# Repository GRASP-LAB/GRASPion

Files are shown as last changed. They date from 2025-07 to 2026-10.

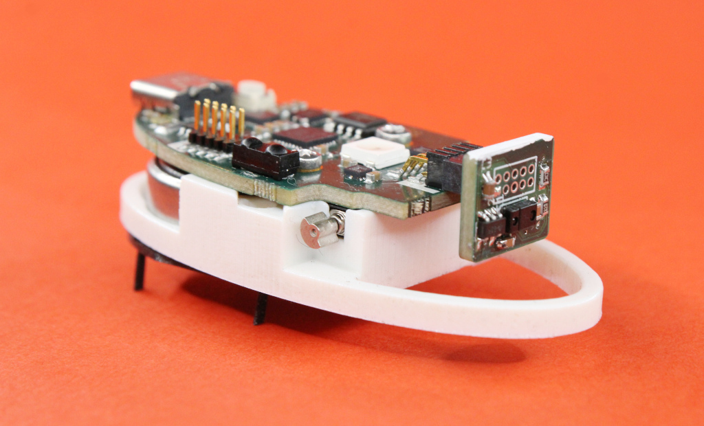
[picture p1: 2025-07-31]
images/bot.jpg

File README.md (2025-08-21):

# GRASPion
The GRASPion is an intelligent bristlebot deisgned for research and education purposes based around
the Adafruit QTPy SAMD21, making it extremely easy-to-use through the Arduino environment. It relies
on two vibrating motors embedded in the bot to move around, and thanks to the carefuly design of its
body and legs available here, it can execute controlled trajectories, by moving straight or turning,
making it a new platform for the experimental study of active matter. It achieves higher velocities
(approx. 15 cm/s) and is capable of higher computing power, than previous types of such bots.



The physical properties of the bot and the results of the examples in this repository are given in
our technical paper (see here). The GRASPion, with a printed and fully assembled circuit board, 3D
printed body, battery, motors and legs is available for order through
[graspion.be](https://graspion.be).

## 3D printing
The bot is made out of three 3D printed objects: the chassis, the legs and the wedge plate in
between them. The STL files of the thre can be found in the printing directory.

### The chassis
The chassis (or the body) is printed out of ABS plastic using the Stratasys J35 PolyJet
printer. This allows for a high resolution print, needed in order to properly fit the vibrating
motors and the battery, and giving a hard body to the robot in order to handle eventual collisions.

### The legs
The legs and wedge plate are printed out of PLA, and we find that the Prusament PLA Prusa Galaxy
handles well and gives consistently reproducible results, using the Prusa XL printer, on the
Structural setting, with 15% infill. It is very important that the legs are printed one-by-one, and
not multiple legs at the same time, since this significantly alters layer adhesion and finally
flexibility of the legs. The wedge plate is printed using the same material.

## Arduino setup

We recommend using the legay Arduino IDE (1.8.19). In order to compile and upload the sketch, you
will need to use the following settings:

| Setting | Value |
| --- | --- |
| Board | Adafruit QT Py M0(SAMD21) ([see here](https://learn.adafruit.com/add-boards-arduino-v164/setup))|
| Optimization |  Ofast  |
| USB Stack |  TinyUSB  |

The libraries that are needed to sucessfully compile the code are:

| Library | Link |
| --- | --- |
| Adafruit Neopixel | https://github.com/adafruit/Adafruit_NeoPixel |
| Adafruit DMA neopixel | https://github.com/adafruit/Adafruit_NeoPixel_ZeroDMA  |
| Adafruit_APDS9960 | https://github.com/adafruit/Adafruit_APDS9960 |
| Adafruit_MLX90393 | https://github.com/adafruit/Adafruit_MLX90393_Library  |
| Adafruit Unified Sensor | https://github.com/adafruit/Adafruit_Sensor |
| Adafruit_BusIO | https://github.com/adafruit/Adafruit_BusIO |
| Arduino-IRremote | https://github.com/Arduino-IRremote/Arduino-IRremote |

The bot has to be turned on in order to compile. In order for the port to appear, it is enough to press the power 
button once. The battery isn't required in order to upload the firmware. Caveat: if the board is removed from the body and 
disconnected from the batter, and subsequently reassembled, the bot needs to be plugged into a charger or live USB-C
cable in order for it to start running again.

## Code examples

Two code examples have been included in the examples directory, one which includes basic remote
control along with a preprogrammed diffusuive motion, and a second one which includes color emission
and synchronization (see PDF for details), Along with these examples, an bash upload script is
included to facilitate uploading to large numbers of bots through the use of a USB hub. The upload
script relies on [arduino-cli](https://github.com/arduino/arduino-cli), which can easily be
installed on Linux distributions.

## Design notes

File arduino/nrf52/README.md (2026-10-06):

# GRASPion Head nRF52832 Arduino support

This directory contains the Arduino support files for the nRF52832 / u-blox ANNA-B112 used in the GRASPion Head.

GRASPion uses three microcontrollers:

- SAMD21 — Body controller
- STM32U575 — Head main controller
- nRF52832 / ANNA-B112 — Head wireless controller

The nRF52 package is based on the Adafruit nRF52 Arduino core 1.7.0 and adds the `graspionHead` board variant.

## GRASPion Head nRF52832 pin mapping

### LED

- P0.15 — built-in LED

### Application UART to STM32U575

- P0.27 TX -> STM32 PA3 / LPUART1_RX
- P0.28 RX <- STM32 PA2 / LPUART1_TX

### Bootloader DFU UART

- P0.29 TX
- P0.30 RX
- 115200 baud

The bootloader UART is intentionally different from the application UART.

### I2C

- P0.16 — SDA
- P0.18 — SCL

### I2S slave RX

- P0.03 — SD / DI
- P0.02 — WS / LRCK
- P0.31 — SCK / BCLK

### Low-frequency clock

The GRASPion Head does not use an external 32.768 kHz crystal for the ANNA-B112. The variant therefore uses the nRF52832 internal LF RC oscillator (`USE_LFRC`).

## Arduino Boards Manager installation

After the first package release has been generated, add this URL to **Arduino IDE -> Preferences -> Additional Boards Manager URLs**:

```text
https://raw.githubusercontent.com/GRASP-LAB/GRASPion/main/package_graspion_index.json
```

Then open **Boards Manager**, search for **GRASPion**, install the package and select:

```text
GRASPion Head nRF52832
```

## Building a package release

The workflow `.github/workflows/build-graspion-nrf52-package.yml` creates the Boards Manager package.

From GitHub:

1. Open **Actions**.
2. Select **Build GRASPion nRF52 Arduino package**.
3. Select **Run workflow**.
4. Enter the package version, for example `1.0.0`.

The workflow:

1. downloads Adafruit nRF52 Arduino core 1.7.0;
2. appends the GRASPion Head board definition;
3. injects `variants/graspionHead`;
4. builds the `.tar.bz2` platform archive;
5. calculates its SHA-256 checksum and size;
6. creates or updates the GitHub release;
7. updates `package_graspion_index.json`.

## Source files

- `variants/graspionHead/variant.h` — board pin/peripheral definitions
- `variants/graspionHead/variant.cpp` — Arduino pin-to-nRF GPIO mapping and variant initialization
- `graspionHead.boards.txt` — board definition appended to Adafruit `boards.txt` during packaging
- `build_package.py` — package/index generator

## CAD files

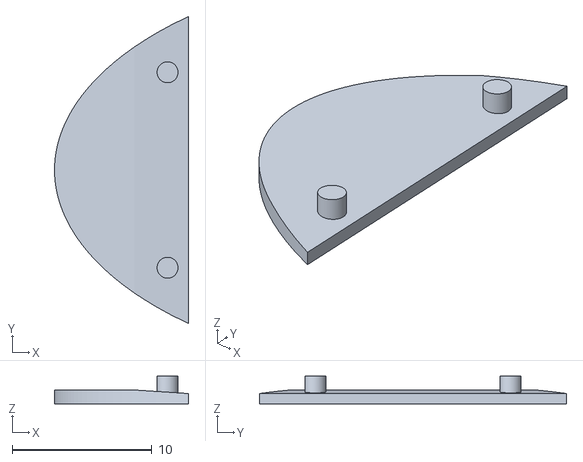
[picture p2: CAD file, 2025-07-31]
prints/Wedge plate.stl
9.60 x 22.0 x 2.00

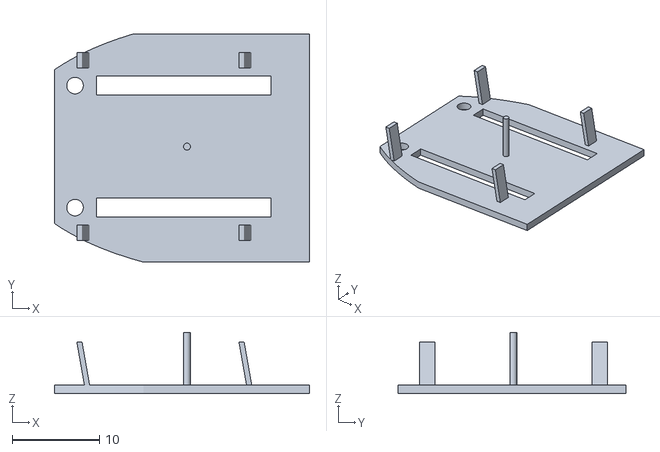
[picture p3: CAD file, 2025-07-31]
prints/Leg plate - rectangular.stl
29.3 x 26.2 x 7.00

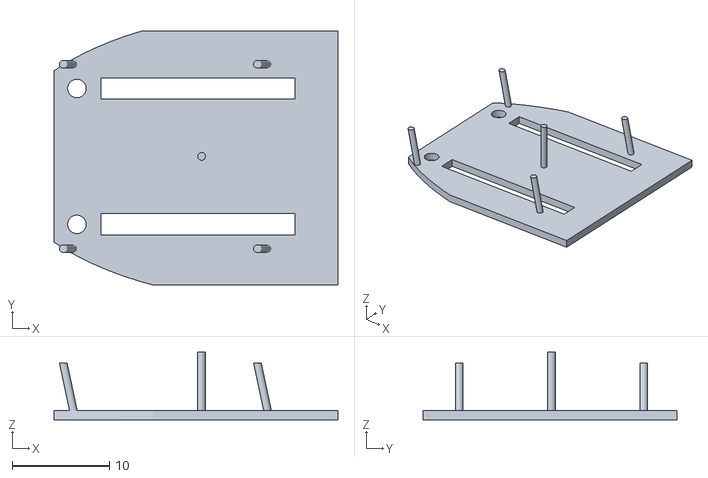
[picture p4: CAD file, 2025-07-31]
prints/Leg plate - circular.stl
29.3 x 26.2 x 7.00

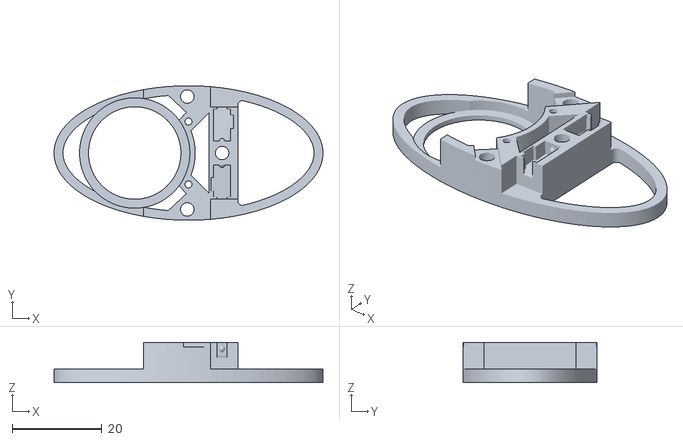
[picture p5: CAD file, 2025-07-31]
prints/GRASPion body.stl
60.0 x 30.0 x 9.00

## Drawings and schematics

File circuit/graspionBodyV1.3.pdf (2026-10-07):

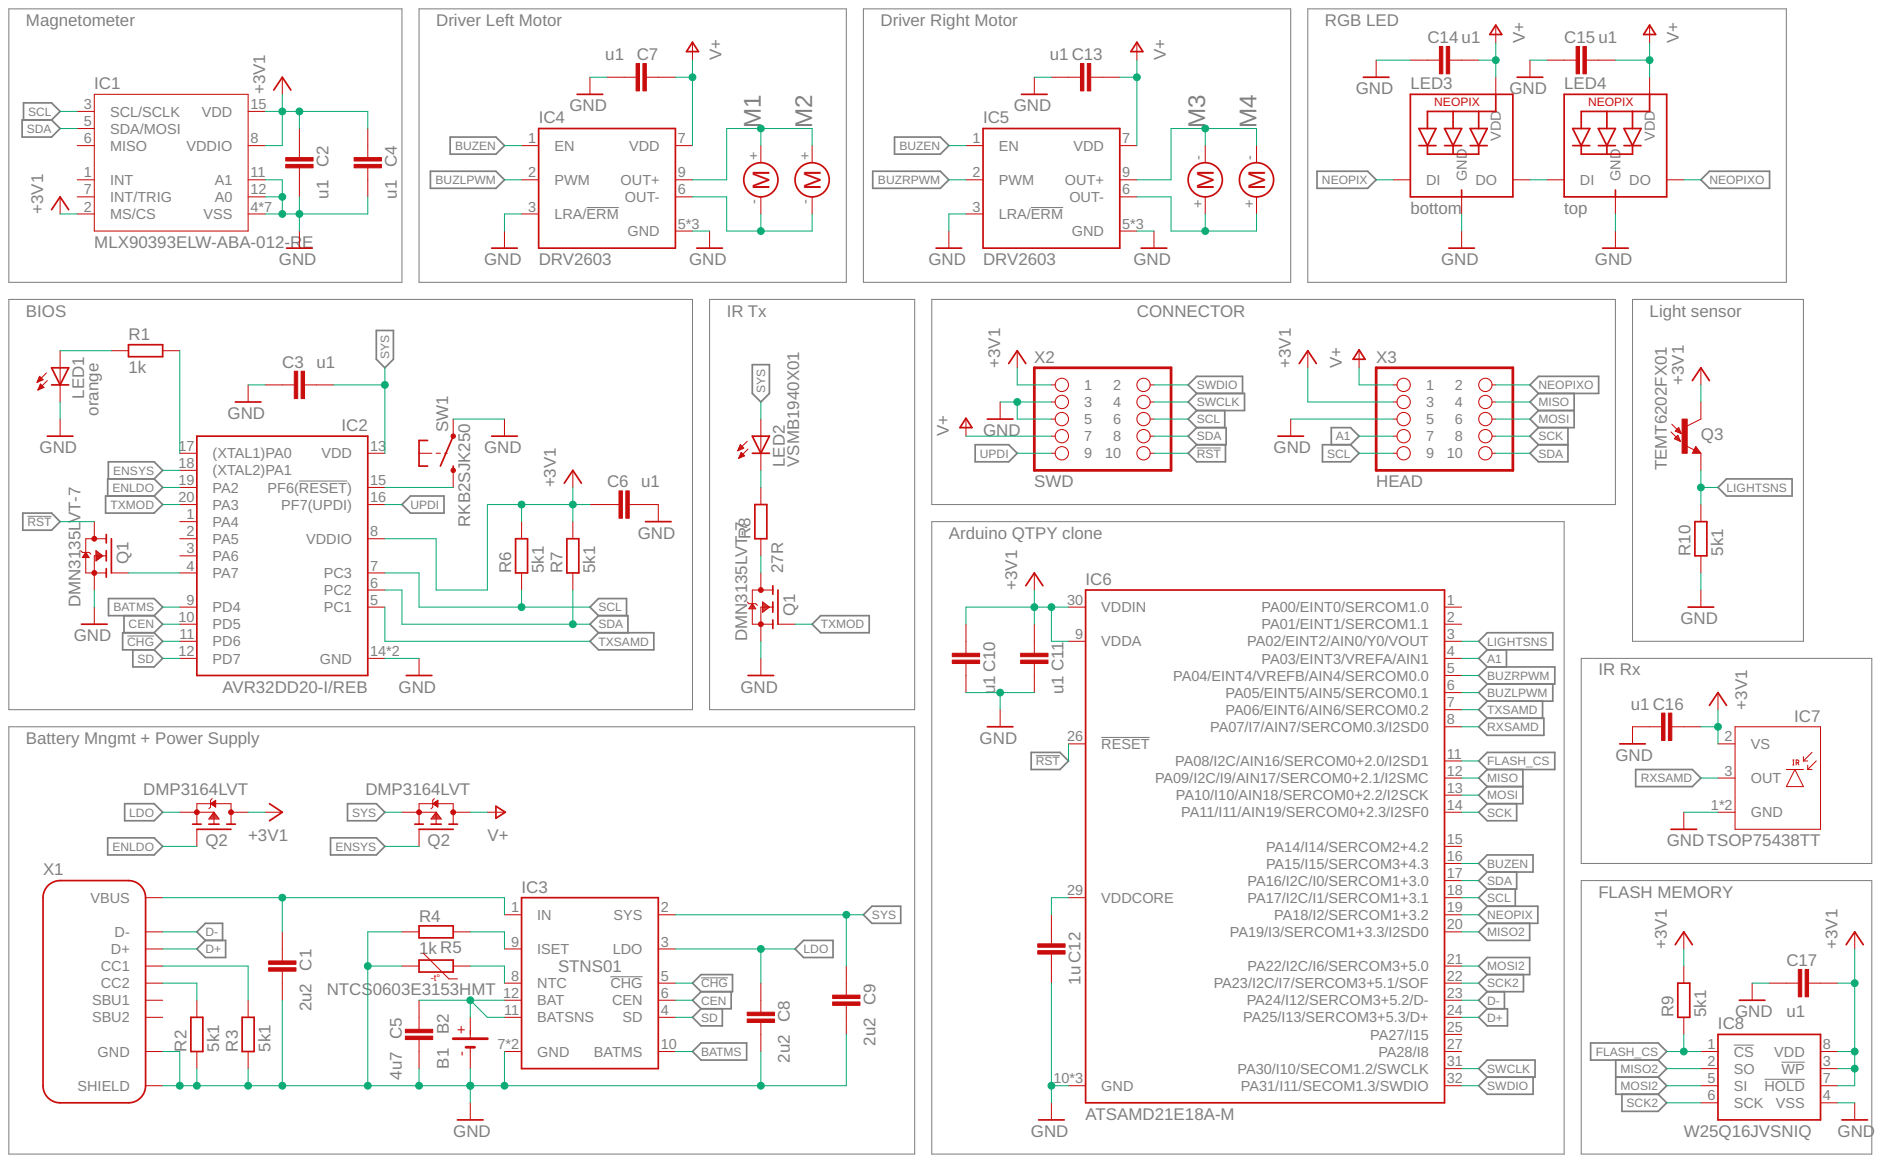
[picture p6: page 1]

Battery Mngmt + Power Supply

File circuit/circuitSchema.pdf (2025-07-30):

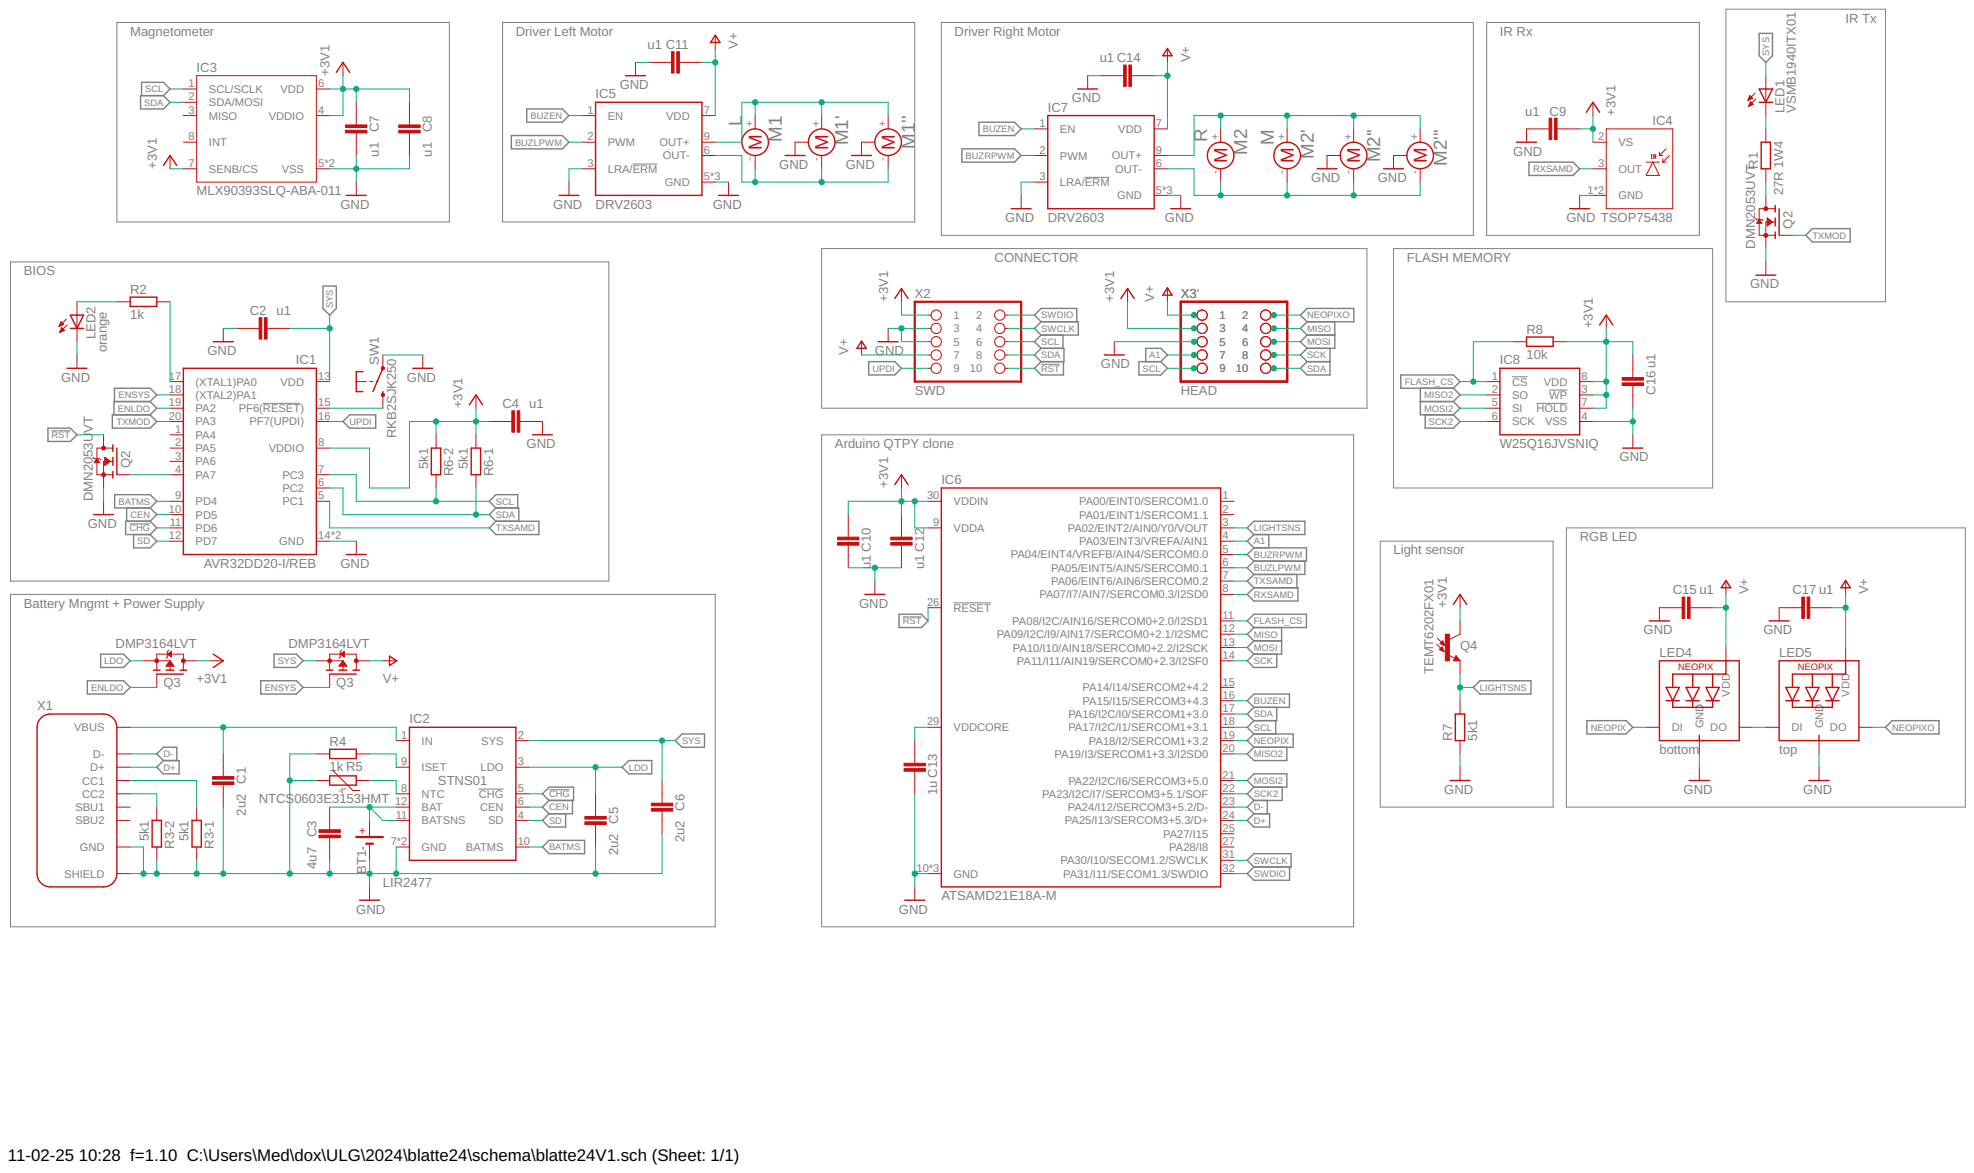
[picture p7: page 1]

Battery Mngmt + Power Supply

11-02-25 10:28 f=1.10 C:\Users\Med\dox\ULG\2024\blatte24\schema\blatte24V1.sch (Sheet: 1/1)

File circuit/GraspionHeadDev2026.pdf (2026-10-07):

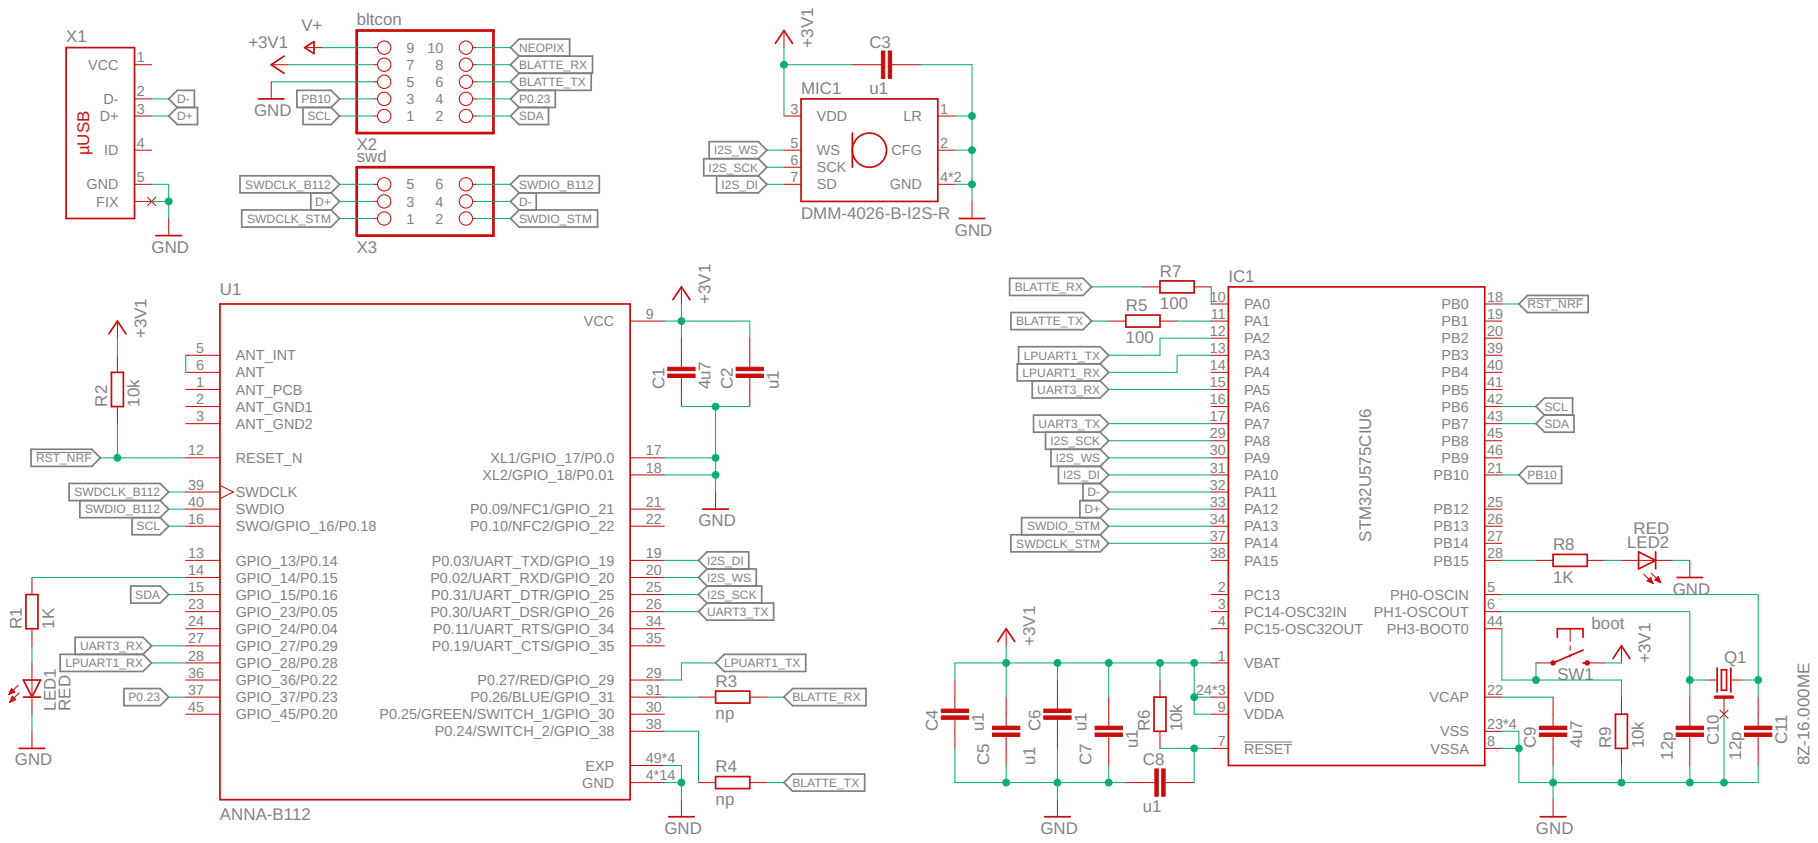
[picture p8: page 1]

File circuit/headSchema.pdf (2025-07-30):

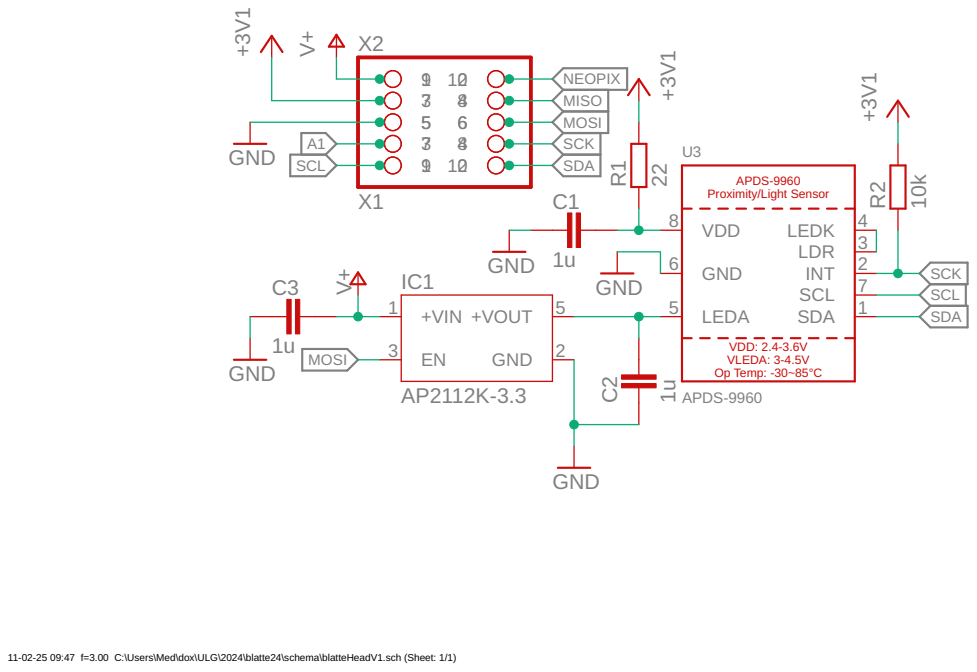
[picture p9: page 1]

11-02-25 09:47 f=3.00 C:\Users\Med\dox\ULG\2024\blatte24\schema\blatteHeadV1.sch (Sheet: 1/1)

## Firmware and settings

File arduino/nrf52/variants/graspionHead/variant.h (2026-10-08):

#ifndef _VARIANT_GRASPIONHEAD_
#define _VARIANT_GRASPIONHEAD_

/*
 * Graspion Head
 * ANNA-B112 / nRF52832
 */

#define VARIANT_MCK (64000000ul)

/*
 * No external 32.768 kHz crystal on Graspion Head.
 * Use internal LF RC oscillator.
 */
#define USE_LFRC

#include "WVariant.h"

#ifdef __cplusplus
extern "C"
{
#endif

/*------------------------------------------------------------------*/
/* Pins
 *------------------------------------------------------------------*/

#define PINS_COUNT           (32u)
#define NUM_DIGITAL_PINS     (32u)
#define NUM_ANALOG_INPUTS    (8u)
#define NUM_ANALOG_OUTPUTS   (0u)

/*------------------------------------------------------------------*/
/* LED
 *
 * P0.15
 *------------------------------------------------------------------*/

#define PIN_LED1             (15)
#define LED_BUILTIN          PIN_LED1
#define LED_BLUE             PIN_LED1
#define LED_STATE_ON         1

/*------------------------------------------------------------------*/
/* Analog inputs
 *
 * nRF52832 SAADC:
 *
 * AIN0 = P0.02
 * AIN1 = P0.03
 * AIN2 = P0.04
 * AIN3 = P0.05
 * AIN4 = P0.28
 * AIN5 = P0.29
 * AIN6 = P0.30
 * AIN7 = P0.31
 *
 * Some of these pins are also assigned to other peripherals on the
 * Graspion Head PCB.
 *------------------------------------------------------------------*/

#define PIN_A0               (2)
#define PIN_A1               (3)
#define PIN_A2               (4)
#define PIN_A3               (5)
#define PIN_A4               (28)
#define PIN_A5               (29)
#define PIN_A6               (30)
#define PIN_A7               (31)

static const uint8_t A0 = PIN_A0;
static const uint8_t A1 = PIN_A1;
static const uint8_t A2 = PIN_A2;
static const uint8_t A3 = PIN_A3;
static const uint8_t A4 = PIN_A4;
static const uint8_t A5 = PIN_A5;
static const uint8_t A6 = PIN_A6;
static const uint8_t A7 = PIN_A7;

#define ADC_RESOLUTION       14

/*------------------------------------------------------------------*/
/* NFC
 *------------------------------------------------------------------*/

#define PIN_NFC1             (9)
#define PIN_NFC2             (10)

/*------------------------------------------------------------------*/
/* Single application UART: Serial
 *
 * nRF52832 exposes one UARTE peripheral through the Adafruit core.
 * GRASPion therefore defines only Serial; no Serial1/Serial2 pins are
 * declared by this variant.
 *
 * nRF P0.29 TX -> STM32 RX
 * nRF P0.30 RX <- STM32 TX
 *------------------------------------------------------------------*/

#define PIN_SERIAL_TX        (29)
#define PIN_SERIAL_RX        (30)

/*------------------------------------------------------------------*/
/* I2C
 *
 * SDA = P0.16
 * SCL = P0.18
 *------------------------------------------------------------------*/

#define WIRE_INTERFACES_COUNT 1

#define PIN_WIRE_SDA         (16u)
#define PIN_WIRE_SCL         (18u)

static const uint8_t SDA = PIN_WIRE_SDA;
static const uint8_t SCL = PIN_WIRE_SCL;

/*------------------------------------------------------------------*/
/* SPI
 *
 * No default SPI bus assigned yet.
 *------------------------------------------------------------------*/

#define SPI_INTERFACES_COUNT 0

/*------------------------------------------------------------------*/
/* I2S - slave RX only
 *
 * DI / SD   = P0.03
 * WS / LRCK = P0.02
 * SCK/BCLK  = P0.31
 *
 * MCK is not used.
 *------------------------------------------------------------------*/

#define I2S_INTERFACES_COUNT 1

#define PIN_I2S_SD           (3u)
#define PIN_I2S_FS           (2u)
#define PIN_I2S_SCK          (31u)

#ifdef __cplusplus
}
#endif

#endif // _VARIANT_GRASPIONHEAD_

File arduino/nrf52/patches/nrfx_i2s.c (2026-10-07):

/**
 * Copyright (c) 2015 - 2021, Nordic Semiconductor ASA
 *
 * All rights reserved.
 *
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
 * 3. Neither the name of Nordic Semiconductor ASA nor the names of its
 *    contributors may be used to endorse or promote products derived from this
 *    software without specific prior written permission.
 *
 * 4. This software, with or without modification, must only be used with a
 *    Nordic Semiconductor ASA integrated circuit.
 *
 * 5. Any software provided in binary form under this license must not be reverse
 *    engineered, decompiled, modified and/or disassembled.
 *
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
 */

#include <nrfx.h>

#if NRFX_CHECK(NRFX_I2S_ENABLED)

#include <nrfx_i2s.h>
#include <hal/nrf_gpio.h>

#define NRFX_LOG_MODULE I2S
#include <nrfx_log.h>

#define EVT_TO_STR(event)                                         \
    (event == NRF_I2S_EVENT_RXPTRUPD ? "NRF_I2S_EVENT_RXPTRUPD" : \
    (event == NRF_I2S_EVENT_TXPTRUPD ? "NRF_I2S_EVENT_TXPTRUPD" : \
    (event == NRF_I2S_EVENT_STOPPED  ? "NRF_I2S_EVENT_STOPPED"  : \
                                       "UNKNOWN EVENT")))

#if !defined(USE_WORKAROUND_FOR_I2S_STOP_ANOMALY) &&                               \
    (defined(NRF52832_XXAA) || defined(NRF52832_XXAB) || defined(NRF52840_XXAA) || \
     defined(NRF9160_XXAA))
#define USE_WORKAROUND_FOR_I2S_STOP_ANOMALY 1
#endif

typedef struct
{
    nrfx_i2s_data_handler_t handler;
    nrfx_drv_state_t        state;

    bool use_rx         : 1;
    bool use_tx         : 1;
    bool rx_ready       : 1;
    bool tx_ready       : 1;
    bool buffers_needed : 1;
    bool buffers_reused : 1;

    uint16_t            buffer_size;
    nrfx_i2s_buffers_t  next_buffers;
    nrfx_i2s_buffers_t  current_buffers;
} i2s_control_block_t;
static i2s_control_block_t m_cb;

static void configure_pins(nrfx_i2s_config_t const * p_config)
{
    uint32_t mck_pin, sdout_pin, sdin_pin;

    if (p_config->mode == NRF_I2S_MODE_MASTER)
    {
        nrf_gpio_cfg_output(p_config->sck_pin);
        nrf_gpio_cfg_output(p_config->lrck_pin);
    }
    else
    {
        nrf_gpio_cfg_input(p_config->sck_pin,  NRF_GPIO_PIN_NOPULL);
        nrf_gpio_cfg_input(p_config->lrck_pin, NRF_GPIO_PIN_NOPULL);
    }

    if (p_config->mck_pin != NRFX_I2S_PIN_NOT_USED)
    {
        mck_pin = p_config->mck_pin;
        nrf_gpio_cfg_output(mck_pin);
    }
    else
    {
        mck_pin = NRF_I2S_PIN_NOT_CONNECTED;
    }

    if (p_config->sdout_pin != NRFX_I2S_PIN_NOT_USED)
    {
        sdout_pin = p_config->sdout_pin;
        nrf_gpio_cfg_output(sdout_pin);
    }
    else
    {
        sdout_pin = NRF_I2S_PIN_NOT_CONNECTED;
    }

    if (p_config->sdin_pin != NRFX_I2S_PIN_NOT_USED)
    {
        sdin_pin = p_config->sdin_pin;
        nrf_gpio_cfg_input(sdin_pin, NRF_GPIO_PIN_NOPULL);
    }
    else
    {
        sdin_pin = NRF_I2S_PIN_NOT_CONNECTED;
    }

    nrf_i2s_pins_set(NRF_I2S,
                     p_config->sck_pin,
                     p_config->lrck_pin,
                     mck_pin,
                     sdout_pin,
                     sdin_pin);
}

nrfx_err_t nrfx_i2s_init(nrfx_i2s_config_t const * p_config,
                         nrfx_i2s_data_handler_t   handler)
{
    NRFX_ASSERT(p_config);
    NRFX_ASSERT(handler);

    nrfx_err_t err_code;

    if (m_cb.state != NRFX_DRV_STATE_UNINITIALIZED)
    {
        err_code = NRFX_ERROR_INVALID_STATE;
        NRFX_LOG_WARNING("Function: %s, error code: %s.",
                         __func__,
                         NRFX_LOG_ERROR_STRING_GET(err_code));
        return err_code;
    }

    if (!nrf_i2s_configure(NRF_I2S,
                           p_config->mode,
                           p_config->format,
                           p_config->alignment,
                           p_config->sample_width,
                           p_config->channels,
                           p_config->mck_setup,
                           p_config->ratio))
    {
        err_code = NRFX_ERROR_INVALID_PARAM;
        NRFX_LOG_WARNING("Function: %s, error code: %s.",
                         __func__,
                         NRFX_LOG_ERROR_STRING_GET(err_code));
        return err_code;
    }
    configure_pins(p_config);

    m_cb.handler = handler;

    NRFX_IRQ_PRIORITY_SET(I2S_IRQn, p_config->irq_priority);
    NRFX_IRQ_ENABLE(I2S_IRQn);

    m_cb.state = NRFX_DRV_STATE_INITIALIZED;

    NRFX_LOG_INFO("Initialized.");
    return NRFX_SUCCESS;
}

void nrfx_i2s_uninit(void)
{
    NRFX_ASSERT(m_cb.state != NRFX_DRV_STATE_UNINITIALIZED);

    nrfx_i2s_stop();

    NRFX_IRQ_DISABLE(I2S_IRQn);

    nrf_i2s_pins_set(NRF_I2S,
                     NRF_I2S_PIN_NOT_CONNECTED,
                     NRF_I2S_PIN_NOT_CONNECTED,
                     NRF_I2S_PIN_NOT_CONNECTED,
                     NRF_I2S_PIN_NOT_CONNECTED,
                     NRF_I2S_PIN_NOT_CONNECTED);

    m_cb.state = NRFX_DRV_STATE_UNINITIALIZED;
    NRFX_LOG_INFO("Uninitialized.");
}
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

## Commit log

2025-07-31 Adding the STLs
    [GRASPion body.stl, Leg plate - circular.stl, Leg plate - rectangular.stl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]
2025-08-21 Print settings
2026-10-06 Add GRASPion Head nRF52832 Arduino support
    Add the GRASPion Head nRF52832 variant, board definition, package builder, GitHub Actions workflow, and installation documentation.
2026-10-06 Fix nRF52 board menu declarations
2026-10-07 Add nrfx I2S driver patch
2026-10-07 Clarify single Serial UART in GRASPion Head variant
2026-10-07 Fix GRASPion Head Serial UART pins
    [variant.h]
2026-10-08 Add LED_BLUE alias for Bluefruit compatibility
2026-10-13 Add SAMD board definitions
2026-10-13 Propose updated Arduino setup documentation
2026-10-15 Update GRASPion Body variant, example and schematic
2026-10-15 Remove broken GRASPion Body schematic PDF
2026-10-15 Bundle GRASPion examples and Arduino libraries
2026-10-15 Document bundled GRASPion Arduino libraries
2026-10-15 Document bundled Arduino libraries
2026-10-16 Clarify MLX90393 I2C address
    Added comment to clarify MLX90393 I2C address definition.
